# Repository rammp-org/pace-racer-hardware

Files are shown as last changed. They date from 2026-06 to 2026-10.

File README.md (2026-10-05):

# PACE Racer motor controller (KiCad hardware)
Welcome to the official hardware repository for the **PACE V0 (RACER)** motor controller board. This repository contains all KiCad design schematics, layout files, and hardware documentation required to manufacture, test, and interface with the RACER platform. 
The companion firmware for this board is under active development in the companion repository: `pace-racer-firmware`.

**How this repo works:** humans commit KiCad sources; CI (KiBot) runs ERC and DRC on every PR and builds gerbers, BOM, position, ibom, PDFs, STEP and renders. Tagging `VnRm` publishes those as a GitHub Release. See `docs/style-guide.md` for conventions and `docs/decisions/` for the why behind unusual choices.
<div align="center">
PaceRacerV0R1 Splash2

## Documentation & Resources
### Access the [schematics and an interactive board viewer here!](https://kicanvas.org/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)
<a href="https://kicanvas.org/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">
  Access Interactive KiCanvas Board Viewer & Schematics
</a>
---

<div align="left">

## Hardware Architecture Overview

The PACE V0 (RACER) is a high-performance, intelligent 3-phase inverter platform powered by an ESP32-S3. It is engineered to support both high-frequency **Field-Oriented Control (FOC)** and traditional **Trapezoidal (Block) Commutation** strategies. 

``` mermaid
flowchart TD
    %% Upstream USB Environment
    subgraph Upstream ["Upstream Side (Isolated USB Environment)"]
        USB["USB-C Connector<br>(USB1)"] -->|VBUS / GND_USB| VUSB["+5V-USB Rail<br>& GND-USB Rail"]
        VUSB -->|Powers Upstream Side| ISO_In["ADUM3160 Digital Isolator<br>(U4 Upstream Pins)"]
    end

    %% Galvanic Isolation Barrier
    subgraph Barrier ["Galvanic Isolation Boundary"]
        ISO_In -.->|Optical/Magnetic Data Isolation| ISO_Out["ADUM3160 Digital Isolator<br>(U4 Downstream Pins)"]
        SW3{"SW3 Switch<br>(DPDT)"}
    end

    %% High Voltage Input Power Stage
    subgraph HV_Stage ["High-Voltage Input Power Stage"]
        BATT["+BATT Input Rail<br>(48V Nominal Target)"] --> Caps["DC-Link Capacitor Buffers<br>(100V Continuous Rating Limit)"]
        Caps --> XLBuck["XL7015E1 Buck Converter<br>(U6 Stage)"]
    end

    %% Main Logic Subsystems
    subgraph Logic_Rails ["Downstream Logic & Control Subsystem"]
        XLBuck -->|Step Down| V5["+5V Local Rail"]
        
        V5 -->|Linear Regulation| AMS["AMS1117-3.3 LDO (U5)"]
        AMS -->|Logic Power| V33["+3V3 Main MCU Rail"]
        
        V5 -->|Precision Division| REF["REF35160 Reference IC (U7)"]
        REF -->|ADC Baseline Shift| V16["1V6-REF Precision Rail"]
        
        V33 -->|Powers MCU| MCU["ESP32-S3 Processing Core<br>(System GND)"]
        V16 -->|Shunt Offset Bias| MCU
        ISO_Out -->|Isolated USB Signals| MCU
    end

    %% Isolation Mode Controls
    VUSB -->|Route Bus Voltage| SW3
    SW3 -->|Flipped State: Breaks Ground Loops| Logic_Rails
```

### 1. Processing & Inverter Stage
* **Core MCU**: An ESP32-S3-WROOM-1 module handles raw motor control mathematics, wireless telemetry, and hardware interrupt management.
* **Gate Driver**: A TI DRV8353SRTAT 3-phase gate driver provides independent high-side/low-side drive configurations, hardware fault line triggers, and runtime register adjustments via SPI.
* **Power MOSFETs**: 6x ISC0802NLSATMA1 MOSFETs are structured in a traditional 3-phase half-bridge bridge array.
* **Current Sensing**: Dual-purpose inline, low-side 1.0 mΩ current sense shunts (`R1`, `R2`, `R3`) are deployed on all three phases to capture fast current waveforms for precision FOC.

### 2. Sensor Framework
* **Rotor Position Feedback**: Supports dual encoder paradigms:
  * High-speed SPI telemetry via the MT6701 Magnetic Rotary Encoder interface.
  * Discrete input lines for standard 3-phase Hall effect sensor elements (`hall-a`, `hall-b`, `hall-c`).
* **Thermal Management**: 4x LM75ADP I2C digital temperature monitors are distributed across key thermal zones on a single I2C bus. Fixed hardware addressing assigns them respectively to `0x4C`, `0x4D`, `0x4E`, and `0x4F`.

### 3. Communications & Safety
* **Wired Networking**: A Wiznet W5500 Ethernet Coprocessor configuration allows stable, high-throughput network communication over a shared high-speed SPI bus.
* **Galvanic Isolation**: The upstream USB-C debugging connection features an ADUM3160BRWZ-RL digital isolation chip to safely separate logic lines from high-voltage battery transient grounds (see `docs/decisions/0001-ground-domains.md`) during live tuning.

---

## Hardware Pin Mapping Reference

This table is generated from the schematic netlist by `tools/gen_readme.py` and checked in CI. Do not edit it by hand.
Net names follow `docs/style-guide.md` (lowercase domain-kebab); the firmware `hal_pins.h` should use these names.

<!-- BEGIN GENERATED: pinmap -->
| MCU pin | Net | Connected to |
| :-- | :-- | :-- |
| IO0/st-boot (pin 27) | `mcu-boot` | R8, SW1 |
| RXD0 (pin 36) | `uart-rx` | J4 |
| TXD0 (pin 37) | `uart-tx` | J4 |
| IO1/adc1-0 (pin 39) | `vref-1v6` | C23, C27, TP24, U2, U7 |
| IO2/adc1-1 (pin 38) | `mcu-io2` | J4 |
| IO3/st-jtag/adc1-2 (pin 15) | `hall-a` | C42, R34 |
| IO4/adc1-3 (pin 4) | `isense-a` | C30, R10 |
| IO5/adc1-4 (pin 5) | `isense-b` | C29, R21 |
| IO6/adc1-5 (pin 6) | `isense-c` | C28, R22 |
| IO7/adc1-6 (pin 7) | `pwm-c-low` | R26, U2 |
| IO8/adc1-7 (pin 12) | `pwm-a-high` | R31, U2 |
| IO9/adc1-8 (pin 17) | `hall-c` | C40, R25 |
| IO10/adc1-9/FSPI-CS (pin 18) | `eth-spi-cs` | J2, R23 |
| IO11/FSPI-D (pin 19) | `spi-copi` | J2, U2 |
| IO12/FSPI-CLK (pin 20) | `spi-clk` | J2, U2 |
| IO13/FSPI-Q (pin 21) | `spi-cipo` | J2, R17, U2 |
| IO14 (pin 22) | `eth-irq` | J2 |
| IO15 (pin 8) | `pwm-c-high` | R27, U2 |
| IO16 (pin 9) | `pwm-b-low` | R28, U2 |
| IO17 (pin 10) | `pwm-b-high` | R29, U2 |
| IO18 (pin 11) | `pwm-a-low` | R30, U2 |
| IO19/USBD- (pin 13) | `usb-dm` | U4 |
| IO20/USBD+ (pin 14) | `usb-dp` | U4 |
| IO21 (pin 23) | `eth-reset` | J2 |
| IO35 (pin 28) | `enc-spi-cipo` | U12 |
| IO36 (pin 29) | `enc-spi-copi` | J4, U12 |
| IO37 (pin 30) | `enc-spi-clk` | U12 |
| IO38 (pin 31) | `enc-spi-cs` | R24, U12 |
| IO39 (pin 32) | `drv-spi-cs` | U2 |
| IO40 (pin 33) | `drv-fault` | R16, U2 |
| IO41 (pin 34) | `led-green` | D2, J4 |
| IO42 (pin 35) | `led-blue` | D1, J4 |
| IO45/st-spi-v (pin 26) | `i2c-sda` | J4, R39, U10, U11, U8, U9 |
| IO46/st-rom (pin 16) | `hall-b` | C41, R33 |
| IO47 (pin 24) | `drv-enable` | R32, U2 |
| IO48 (pin 25) | `i2c-scl` | J4, R40, U10, U11, U8, U9 |
| EN (pin 3) | `mcu-reset` | R9, SW2 |
<!-- END GENERATED: pinmap -->

---

## Power Distribution & Topology

The RACER PCB layout handles standard heavy industrial current loops alongside sensitive logic rails. Care must be taken during low-level development to understand the distinct ground rules and supply behavior.

* **Main DC Power Stage Input (`+BATT`)**: Accepts high-voltage input up to 60V DC. High and low-frequency buffer capacitor banks are placed immediately across each half-bridge phase to suppress heavy inductive switching ripples up to 25MHz.
* **Logic Subsystem Buck (5V Rail)**: Driven by an XL7015E1 high-voltage buck regulator topology, dropping the high-voltage input down to a common local 5V line.
* **Microcontroller Supply (3.3V Rail)**: An AMS1117-3.3 linear regulator drops the local 5V line to a stable 3.3V rail dedicated to powering the ESP32-S3 and onboard sensors.
* **Analog Ingestion Bias Reference (`vref-1v6`)**: Formed via a REF35160QDBVR high-precision reference generator connected to the 5V line. This outputs a fixed 1.6V reference bias to calibrate the inline current shunt amplifiers, permitting measurement of negative and positive phase currents across the full bi-directional stroke.
* **Isolation Boundary Notice**: The 5V-USB rail is strictly limited to powering the upstream digital isolator components. Flipping the physical isolation switch (`SW3`) cleanly detaches the target ground (`GND`) from development computer USB shields (`GND-USB`) to protect computer infrastructure against high-power faults.

---

## First-Stage Firmware Initialization Blueprint

To quickly bring up prototype firmware on `pace-racer-firmware`, organize your driver initializations using this execution checklist:

### Phase 1: Core Systems & Diagnostic Telemetry
1. Define the physical I/O allocations outlined in the pin reference table.
2. Initialize diagnostic LEDs (`IO41`, `IO42`) to indicate a booting state.
3. Fire up the shared I2C bus over `IO45` and `IO48` to loop and register responses from the four LM75ADP temperature sensor configurations at addresses `0x4C` through `0x4F`. 

### Phase 2: Inverter Protection & Commutation Interfaces
1. Configure `IO40` (`drv-fault`) as an active-low hardware interrupt line. Ensure its handler instantly forces all PWM generation lines into a low (disabled) safety state if triggered.
2. Initialize the main SPI communications bus over pins `spi-copi`, `spi-clk`, and `spi-cipo`. Pull the gate driver chip select (`IO39`) low to configure the DRV8353 operational state registers.
3. For **Field-Oriented Control (FOC)**, configure high-speed SPI capture over the encoder subsystem (`IO35`, `IO37`, `IO38`) to decode magnetic orientation data from the MT6701.
4. For **Trapezoidal Commutation**, establish change-of-state interrupt routines tracking discrete pin changes across Hall effect inputs (`IO3`, `IO46`, `IO9`).

### Phase 3: Ethernet Networking
1. Cycle the hardware reset pin `IO21` to clear the internal registers of the W5500 Ethernet chip.
2. Configure SPI tracking over the controller chip select pin `IO10`.
3. Initialize the raw sockets over network stacks using the standard `eth-irq` (`IO14`) interrupt pin to manage incoming and outgoing network interface events without blocking the high-frequency motor control loops.

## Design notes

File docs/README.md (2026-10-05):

# Documentation

- `media/renders/` — curated board renders and the Blender scene that produced them (Git LFS). The full animation frame set is not tracked; regenerate from the `.blend`.

Planned (see repo hygiene plan):
- `decisions/` — short design decision records (ground topology, isolation switch, each DRC exclusion).
- `style-guide.md` — schematic and layout conventions for the team.
- `bringup.md`, `errata.md` — per-revision bring-up checklist and known issues.

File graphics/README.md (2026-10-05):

# Brand and logo assets

Logo and silkscreen artwork used on the board and in documentation.

- `svg/` — vector logos (RAMMP, ATDev, PaceRacer, DuckSpark, RotoDuk). Import these into KiCad via the Image Converter for silkscreen.
- `png-1x/`, `png-128w/` — raster exports of the above.
- `rotoduck/` — RotoDuk logo rotation sweep (SVG + PNG).
- `src/` — Photoshop source files, stored via Git LFS.

These are not KiCad project files and will move to a shared brand-assets repo once one exists.

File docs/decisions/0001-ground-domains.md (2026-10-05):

# 0001 Ground domains and USB isolation

Status: accepted (V0R1)

The board has two ground nets, not three:

- `GND` is the logic ground and also the power-stage return. The `GNDPWR`
  power symbols on the inverter and power sheets are shorted to `GND` by the
  low-side shunt net ties, so KiCad merges them and ERC reports
  `multiple_net_names`. See 0002.
- `GND-USB` is the upstream, computer-side USB ground. It is separated from
  `GND` by the ADUM3160 digital isolator (U4). The DPDT switch SW3 can bond
  the two grounds for bench work where isolation is not wanted.

Why: a live 48 V power stage with a bench PC attached over USB is the most
common way to destroy a laptop port. Isolation is the default; bonding is a
deliberate switch action.

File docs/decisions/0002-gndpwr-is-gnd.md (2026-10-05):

# 0002 GNDPWR symbols resolve to GND

Status: accepted with an open question

`GNDPWR` symbols are used on the inverter and power sheets to show intent
(power-stage return), but the low-side shunt net ties connect that return to
`GND`, so there is one net. ERC reports one `multiple_net_names` warning for
this and the netlist uses `GND`.

The former `High-Current-GND` net class matched a net (`GND-HC`) that never
existed and was removed in the V1R2 cleanup. The power-stage return relies on
the ground pours, not on a class.

Open question for V2: either replace the `GNDPWR` symbols with `GND` to
silence the warning, or make the split real with a single-point net tie at the
shunts and a dedicated pour. Decide before the next layout change in the
inverter area.

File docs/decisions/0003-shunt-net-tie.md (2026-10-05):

# 0003 Shunt net-tie clearance rule

Status: accepted (V1R2)

The three low-side shunts (R1, R2, R3) use a net-tie footprint (NT1..NT3,
`specific-parts-lib:shunt-net-tie`) to make a Kelvin connection: the sense
net (`shunt-x-n`) and `GND` meet only at the shunt pad. The net-tie pads
intentionally overlap the shunt pads and sit inside the ground pour.

KiCad's default clearance flags those overlaps. Instead of point exclusions
(which were stale after the V1 re-layout), `pace-core.kicad_dru` waives
clearance for anything touching NT1..NT3. The bridge copper inside the
footprint is now part of pad 2 as a custom pad shape, so no free copper
polygon exists and `shorting_items` no longer fires.

Consequence: DRC in CI runs with zero exclusions. If the net tie moves or a
fourth shunt is added, extend the rule condition.

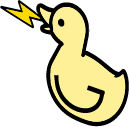
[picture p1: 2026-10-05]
graphics/rotoduck/1x/Generative Object (-180, 30).png

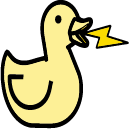
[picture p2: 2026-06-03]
graphics/png-1x/DuckSpark.png

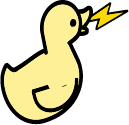
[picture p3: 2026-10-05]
graphics/rotoduck/1x/Generative Object (75, 30).png

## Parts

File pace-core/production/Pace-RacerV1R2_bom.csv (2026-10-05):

Designator | Footprint | Quantity | Value | LCSC Part #
C1, C10, C9 | 0603 | 3 | 100nF
C11, C12, C13 | 1210 | 3 | 4.7uF 100V
C14 | 0603 | 1 | 47nF
C15, C25, C26 | 1206 | 3 | 1uF
C16 | 0402 | 1 | 33nF
C17 | C_Elec_6.3x7.7 | 1 | 100uF 16v | EEEFPV101XAP
C18, C23, C4 | 0603 | 3 | 10uF
C19, C20, C21 | CAP-TH_BD16.0-P7.50-D1.2-FD | 3 | 470uF 100V | C18164658
C2 | 1206 | 1 | 10uF
C24 | 0402 | 1 | 100nF
C27 | 0402 | 1 | .1uF
C28, C29, C30, C40, C41, C42 | 0402 | 6 | 1nF
C3 | 0603 | 1 | 22uF
C31, C32, C33, C34 | 0402 | 4 | 0.1uF
C35 | 1210 | 1 | 2.2uF
C36, C37, C38, C39 | CAP-TH_BD6.3-P2.50-D0.6-FD | 4 | PA100V22M6X9 | C49233038
C6, C7, C8 | 1206 | 3 | 2.2uF 100V
CN1 | CONN-TH_XT60PW-M | 1 | XT60PW-M | C98732
CN2, CN3, CN4, CN5, CN6, CN7 | M3-TH_BD6.0-D4.3 | 6 | SMTSOM330BTR | C5221843
D1 | 0805 | 1 | blue
D2 | 0805 | 1 | green
D3 | 0805 | 1 | red
D4 | D_SMA | 1 | SS310
J1 | 3PhaseMotorPigtail | 1 | MotorOut
J2 | PinSocket_1x09_P2.54mm_Vertical_SMD_Pin1Left | 1 | Wiz5500-Coprocessor-BoB
J4 | PinHeader_2x05_P2.54mm_Vertical_SMD | 1 | Conn_02x05_Odd_Even
L2 | IND-SMD_L10.0-W10.0_SRU1038-100Y | 1 | 100uH 1A | C6684389
Q10, Q11, Q12, Q7, Q8, Q9 | PG-TDSON-8_L5.9-W5.1-P1.27-LS6.1-BL | 6 | ISC0802NLSATMA1 | C3288904
R1, R2, R3 | RES-SMD_L6.3-W3.1-1 | 3 | 1.0mΩ | C41382682
R10, R21, R22, R25, R33, R34 | 0402 | 6 | 100R
R11, R12, R13 | 0402 | 3 | 5k
R14 | 0402 | 1 | 30k 1%
R15 | 0402 | 1 | 10k 1%
R16, R17, R18, R19, R20, R23, R24, R26, R27, R28, R29, R30, R31, R32, R35, R36, R37, R38, R39, R40 | 0402 | 20 | 10k
R4, R5, R8, R9 | 0402 | 4 | 5k1
R6, R7 | 0402 | 2 | 0
SW1, SW2 | KEY-SMD_4P-L4.2-W3.2-P2.20-LS4.6 | 2 | SKRPACE010 | C139797
SW3 | SW-SMD_MST22D18G2 | 1 | DPDT | C2906280
TP18, TP19, TP20, TP24, TP25 | TestPoint_Pad_D2.0mm | 5 | TestPoint
U1 | WIRELM-SMD_ESP32-S3-WROOM-1 | 1 | ESP32-S3-WROOM-1 | C2913205
U10, U11, U8, U9 | TSSOP-8_L3.0-W3.0-P0.65-LS4.9-BL | 4 | LM75ADP,118 | C843694
U12, U13 | CONN-SMD_SM06B-SRSS-TB-LF-SN | 2 | SM06B-SRSS-TB | C160405
U2 | WQFN-40_L6.0-W6.0-P0.50-TL-EP4.2 | 1 | DRV8353SRTAT | C2150480
U3 | SOT-666 | 1 | USBLC6-2P6
U4 | SOIC-16_L10.3-W7.5-P1.27-LS10.3-BL | 1 | ADUM3160BRWZ-RL | C284149
U5 | SOT-223-3_L6.5-W3.4-P2.30-LS7.0-BR | 1 | AMS1117-3.3 | C6186
U6 | TO-252-5_L6.6-W5.8-P1.27-TL | 1 | XL7015E1 | C73013
U7 | SOT-23-6 | 1 | REF35160QDBVR
USB1 | USB-C-SMD_TYPEC-303-ACP16 | 1 | TYPEC-303-ACP16 | C720628

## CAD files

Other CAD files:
docs/media/renders/racer-v0r1-ethernet.blend

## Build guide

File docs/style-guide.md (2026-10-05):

# Hardware style guide

This is the house style for KiCad projects. It exists so a reviewer can tell
"different" from "wrong" in under a minute. When a rule is broken on purpose,
write a decision record in `docs/decisions/` and link it from the schematic note.

## Repository

- Humans commit sources; CI produces everything else. Never commit gerbers, PDFs,
  STEP, ibom or renders. They come from KiBot on every PR and are attached to a
  GitHub Release on tags.
- Revision scheme is `VnRm` (`V1R2`). The git tag, the `REV` text variable, the
  silkscreen and the fab zip name are all that string. CI sets `REV` from the tag.
- Large binaries (Blender, PSD, video, curated renders) go through Git LFS.
- Every fab release gets a tag, a release and an entry in `docs/errata.md`.
- Close KiCad before scripted or git edits to `.kicad_pro`, `.kicad_sch` or
  `.kicad_pcb`. KiCad rewrites those files from memory on save and will
  silently discard outside changes.

## Schematic

- One subsystem per sheet. Sheet title blocks use `${TITLE} - <Subsystem>`,
  `${REV}`, `${COMPANY}` and a one-line purpose in comment 1.
- Net names are lowercase domain-kebab: `<domain>-<signal>[-<qualifier>]`.
  Examples: `pwm-a-high`, `isense-a`, `hall-b`, `enc-spi-cs`, `eth-irq`,
  `i2c-sda`, `usb-dp`, `vref-1v6`, `mcu-boot`. Power nets keep KiCad style:
  `+BATT`, `+5V`, `+3V3`, `GND`, `GND-USB`.
- Every net that crosses a sheet is a hierarchical pin or a global label; never
  rely on a power symbol as a signal.
- Every symbol carries `Manufacturer`, `MPN`, `LCSC Part`, `Datasheet` and
  `Description`. Blank is allowed only for generic passives, and the BOM step
  will show the blank.
- Every ERC exception has a decision record. ERC errors block merge; warnings
  are triaged into `docs/errata.md`.
- Each sheet has a notes block: purpose, key numbers (voltages, currents,
  frequencies), and the calculations behind component values.
- Custom symbols and footprints live in `specific-parts/`. Anything used on a
  second project gets promoted to the shared library repo.

## Layout

- Stackup is defined in Board Setup and matches the fab's stock stackup.
- Net classes drive track and via sizes. Do not hand-set widths that should be
  a class; if a net needs its own width, it needs its own class.
  Current classes (schematic colour in brackets): `Default` 0.2 mm,
  `GND` 0.356 mm (black), `3V3` 0.356 mm (gold), `5V` 0.356 mm (orange),
  `GND-USB` 0.356 mm (blue), `Batt` 1.0 mm (red), `Motor-A/B/C` 1.0 mm
  (yellow / green / blue, also coloured on the board). Colours are part of
  the house style: they make rail and phase mistakes visible at a glance.
- DRC runs with schematic parity and must have zero errors. Custom rules live
  in `pace-core.kicad_dru` with a comment linking the decision record.
  Point exclusions are not used; they go stale when parts move.
- Silkscreen: reference designators readable at 1 mm text, connector pin 1
  marked, polarity marked, `${REV}` and project name on the top silk.
- Test points are numbered `TP<n>` and listed in `docs/bringup.md`.
- Mechanical exchange goes through `mech/` (outline DXF in, board STEP out).

## Review

- Every design change is a PR. The kiri diff is the first thing a reviewer opens.
- The PR template checklist is the definition of done.

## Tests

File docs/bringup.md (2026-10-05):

# Bring-up checklist

Fill in per board serial. Copy this file to `docs/bringup/<rev>-<serial>.md`.

1. Visual: solder bridges on U1, U2, USB1; polarity on C19..C21, D4.
2. Power off: resistance `+BATT` to `GND` (> 10 kΩ), `+5V` to `GND`, `+3V3` to `GND`.
3. Bench supply 12 V, 100 mA limit on `+BATT`: measure `+5V`, `+3V3`, `vref-1v6`.
4. USB with SW3 in isolated position: ESP32 enumerates; measure `GND-USB` to `GND` (open).
5. Flash firmware, LEDs blink, I2C scan finds `0x4C`..`0x4F`.
6. DRV8353 SPI: read device ID; nFAULT high.
7. Encoder SPI: MT6701 angle reads.
8. Motor, 12 V, no load: open-loop spin each direction; check phase current waveforms.
9. Raise to 48 V; thermal check after 5 min at target current.

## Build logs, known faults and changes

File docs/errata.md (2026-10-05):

# Errata and known warnings

## Known ERC/DRC warnings (not errors)

| Check | Count | Why it is tolerated | Fix planned |
| :-- | :-- | :-- | :-- |
| ERC `pin_to_pin` (Unspecified pins) | ~195 | Imported symbols from EasyEDA carry `unspecified` pin types | Assign pin types when parts are promoted to the shared library |
| ERC `lib_symbol_mismatch` | ~15 | Embedded symbol copies drifted from the library | Run *Update Symbols from Library* in the GUI and commit |
| ERC `multiple_net_names` GND/GNDPWR | 1 | See decisions/0002 | Decide GNDPWR split in V2 |
| DRC `lib_footprint_mismatch` | 6 | Embedded footprints drifted from library (C17, USB1, U6, C19..C21) | Run *Update Footprints from Library* and commit |
| DRC `connection_width` on ground pour | 5 | Thin necks in the pour between vias | Widen pour necks in the next layout pass |

## Open design items

- `C5` (47uF 100V) is deliberately not fitted: the buck converter's bulk input capacitance is shared with the motor-drive DC-link caps (C19..C21). Mark it DNP in the schematic so the BOM and parity stay clean.
- Passives lack MPN and LCSC fields; the BOM shows blanks. Fill from the
  assembly quote when the next order is placed.

## Board revision history

| Rev | Built | Notes |
| :-- | :-- | :-- |
| V0R1 | yes | First article. Fab package archived under production/ until retro-tagged. |
| V1R2 | in progress | Re-packaged connectors and layout. |

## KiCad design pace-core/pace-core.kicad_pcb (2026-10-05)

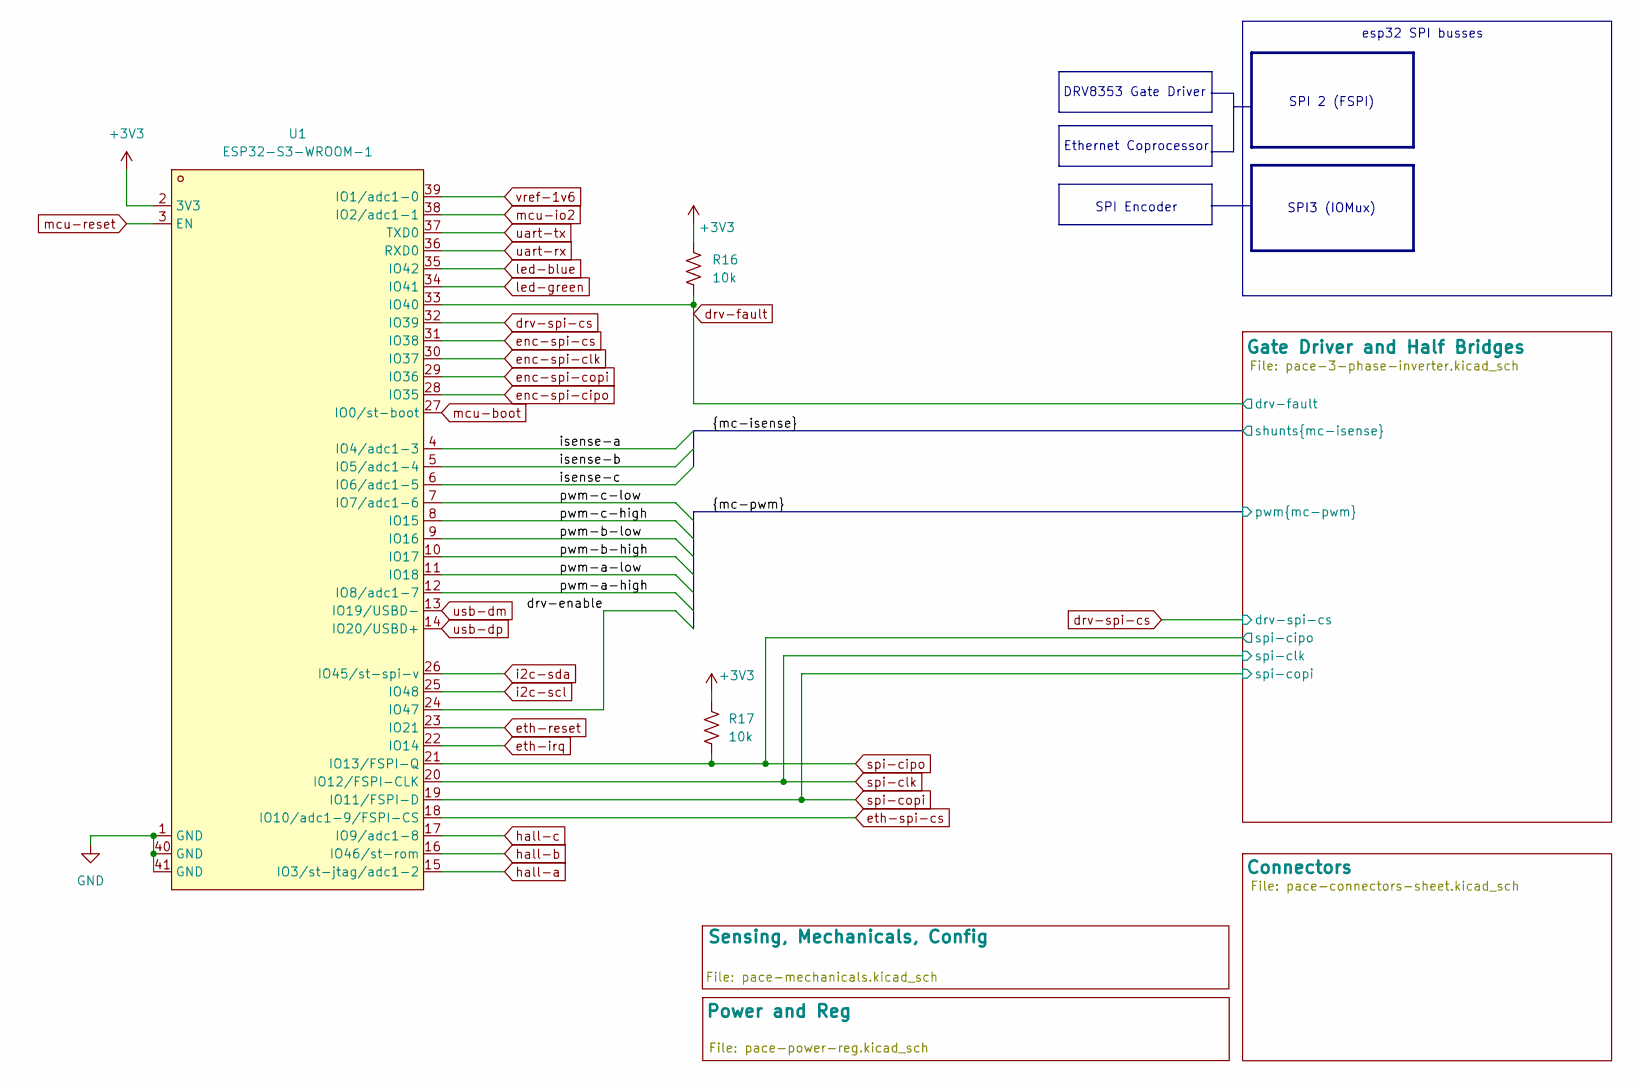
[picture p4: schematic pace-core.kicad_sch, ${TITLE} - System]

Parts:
R16, R17: 10k; R_0402_1005Metric
U1: ESP32-S3-WROOM-1; WIRELM-SMD_ESP32-S3-WROOM-1; MPN ESP32-S3-WROOM-1-N16R2; LCSC Part C2913205

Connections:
+3V3: R16.1, R17.1, U1.2 (3V3); also elsewhere on the board
/drv-enable: U1.24 (IO47); also elsewhere on the board
/isense-a: U1.4 (IO4/adc1-3); also elsewhere on the board
/isense-b: U1.5 (IO5/adc1-4); also elsewhere on the board
/isense-c: U1.6 (IO6/adc1-5); also elsewhere on the board
/pwm-a-high: U1.12 (IO8/adc1-7); also elsewhere on the board
/pwm-a-low: U1.11 (IO18); also elsewhere on the board
/pwm-b-high: U1.10 (IO17); also elsewhere on the board
/pwm-b-low: U1.9 (IO16); also elsewhere on the board
/pwm-c-high: U1.8 (IO15); also elsewhere on the board
/pwm-c-low: U1.7 (IO7/adc1-6); also elsewhere on the board
GND: U1.1 (GND), U1.40 (GND), U1.41 (GND); also elsewhere on the board
drv-fault: R16.2, U1.33 (IO40); also elsewhere on the board
drv-spi-cs: U1.32 (IO39); also elsewhere on the board
enc-spi-cipo: U1.28 (IO35); also elsewhere on the board
enc-spi-clk: U1.30 (IO37); also elsewhere on the board
enc-spi-copi: U1.29 (IO36); also elsewhere on the board
enc-spi-cs: U1.31 (IO38); also elsewhere on the board
eth-irq: U1.22 (IO14); also elsewhere on the board
eth-reset: U1.23 (IO21); also elsewhere on the board
eth-spi-cs: U1.18 (IO10/adc1-9/FSPI-CS); also elsewhere on the board
hall-a: U1.15 (IO3/st-jtag/adc1-2); also elsewhere on the board
hall-b: U1.16 (IO46/st-rom); also elsewhere on the board
hall-c: U1.17 (IO9/adc1-8); also elsewhere on the board
i2c-scl: U1.25 (IO48); also elsewhere on the board
i2c-sda: U1.26 (IO45/st-spi-v); also elsewhere on the board
led-blue: U1.35 (IO42); also elsewhere on the board
led-green: U1.34 (IO41); also elsewhere on the board
mcu-boot: U1.27 (IO0/st-boot); also elsewhere on the board
mcu-io2: U1.38 (IO2/adc1-1); also elsewhere on the board
mcu-reset: U1.3 (EN); also elsewhere on the board
spi-cipo: R17.2, U1.21 (IO13/FSPI-Q); also elsewhere on the board
spi-clk: U1.20 (IO12/FSPI-CLK); also elsewhere on the board
spi-copi: U1.19 (IO11/FSPI-D); also elsewhere on the board
uart-rx: U1.36 (RXD0); also elsewhere on the board
uart-tx: U1.37 (TXD0); also elsewhere on the board
usb-dm: U1.13 (IO19/USBD-); also elsewhere on the board
usb-dp: U1.14 (IO20/USBD+); also elsewhere on the board
vref-1v6: U1.39 (IO1/adc1-0); also elsewhere on the board

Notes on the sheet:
SPI3 (IOMux)
SPI 2 (FSPI)
SPI Encoder
Ethernet Coprocessor
DRV8353 Gate Driver
esp32 SPI busses

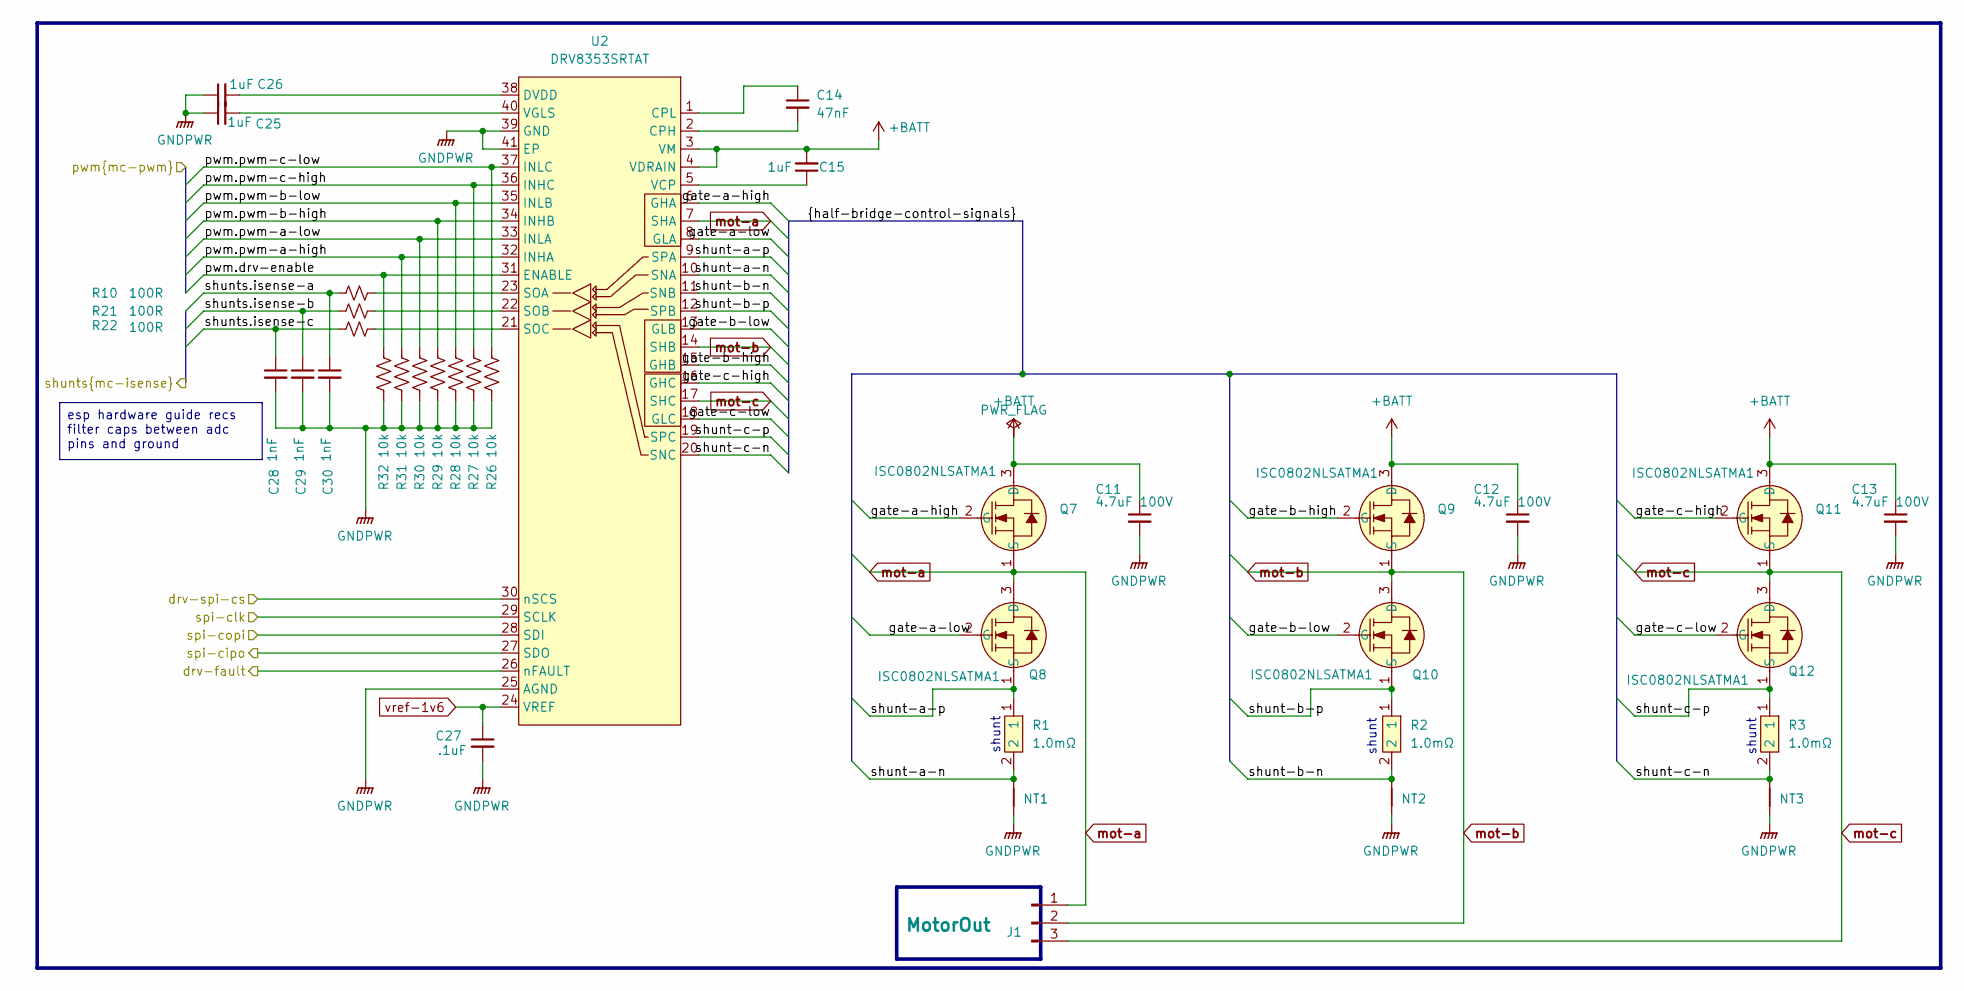
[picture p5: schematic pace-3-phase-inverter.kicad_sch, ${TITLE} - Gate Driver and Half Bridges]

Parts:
C11, C12, C13: 4.7uF 100V; C_1210_3225Metric
C14: 47nF; C_0603_1608Metric
C15, C25, C26: 1uF; C_1206_3216Metric
C27: .1uF; C_0402_1005Metric
C28, C29, C30: 1nF; C_0402_1005Metric
J1: MotorOut; 3PhaseMotorPigtail
NT1, NT2, NT3: NetTie_2; shunt-net-tie
Q7, Q8, Q9, Q10, Q11, Q12: ISC0802NLSATMA1; PG-TDSON-8_L5.9-W5.1-P1.27-LS6.1-BL; MPN ISC0802NLSATMA1; LCSC Part C3288904
R1, R2, R3: 1.0mΩ; RES-SMD_L6.3-W3.1-1; MPN DSLR-M-3-1F; LCSC Part C41382682
R10, R21, R22: 100R; R_0402_1005Metric
R26, R27, R28, R29, R30, R31, R32: 10k; R_0402_1005Metric
U2: DRV8353SRTAT; WQFN-40_L6.0-W6.0-P0.50-TL-EP4.2; MPN DRV8353SRTAT; LCSC Part C2150480

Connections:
+BATT: C11.1, C12.1, C13.1, C15.2, Q7.3 (D), Q9.3 (D), Q11.3 (D), U2.3 (VM), U2.4 (VDRAIN); also elsewhere on the board
/Gate Driver and Half Bridges/gate-a-high: Q7.2 (G), U2.6 (GHA)
/Gate Driver and Half Bridges/gate-a-low: Q8.2 (G), U2.8 (GLA)
/Gate Driver and Half Bridges/gate-b-high: Q9.2 (G), U2.15 (GHB)
/Gate Driver and Half Bridges/gate-b-low: Q10.2 (G), U2.13 (GLB)
/Gate Driver and Half Bridges/gate-c-high: Q11.2 (G), U2.16 (GHC)
/Gate Driver and Half Bridges/gate-c-low: Q12.2 (G), U2.18 (GLC)
/Gate Driver and Half Bridges/shunt-a-n: NT1.2, R1.2, U2.10 (SNA)
/Gate Driver and Half Bridges/shunt-a-p: Q8.1 (S), R1.1, U2.9 (SPA)
/Gate Driver and Half Bridges/shunt-b-n: NT2.2, R2.2, U2.11 (SNB)
/Gate Driver and Half Bridges/shunt-b-p: Q10.1 (S), R2.1, U2.12 (SPB)
/Gate Driver and Half Bridges/shunt-c-n: NT3.2, R3.2, U2.20 (SNC)
/Gate Driver and Half Bridges/shunt-c-p: Q12.1 (S), R3.1, U2.19 (SPC)
/drv-enable: R32.2, U2.31 (ENABLE); also elsewhere on the board
/isense-a: C30.1, R10.1; also elsewhere on the board
/isense-b: C29.1, R21.1; also elsewhere on the board
/isense-c: C28.1, R22.1; also elsewhere on the board
/pwm-a-high: R31.2, U2.32 (INHA); also elsewhere on the board
/pwm-a-low: R30.2, U2.33 (INLA); also elsewhere on the board
/pwm-b-high: R29.2, U2.34 (INHB); also elsewhere on the board
/pwm-b-low: R28.2, U2.35 (INLB); also elsewhere on the board
/pwm-c-high: R27.2, U2.36 (INHC); also elsewhere on the board
/pwm-c-low: R26.2, U2.37 (INLC); also elsewhere on the board
GND: C11.2, C12.2, C13.2, C25.1, C26.1, C27.2, C28.2, C29.2, C30.2, NT1.1, NT2.1, NT3.1, R26.1, R27.1, R28.1, R29.1, R30.1, R31.1, R32.1, U2.25 (AGND), U2.39 (GND), U2.41 (EP); also elsewhere on the board
unnamed: C14.2, U2.2 (CPH)
unnamed: C14.1, U2.1 (CPL)
unnamed: C26.2, U2.38 (DVDD)
unnamed: R10.2, U2.23 (SOA)
unnamed: R21.2, U2.22 (SOB)
unnamed: R22.2, U2.21 (SOC)
unnamed: C15.1, U2.5 (VCP)
unnamed: C25.2, U2.40 (VGLS)
drv-fault: U2.26 (nFAULT); also elsewhere on the board
drv-spi-cs: U2.30 (nSCS); also elsewhere on the board
mot-a: J1.1, Q7.1 (S), Q8.3 (D), U2.7 (SHA)
mot-b: J1.2, Q9.1 (S), Q10.3 (D), U2.14 (SHB)
mot-c: J1.3, Q11.1 (S), Q12.3 (D), U2.17 (SHC)
spi-cipo: U2.27 (SDO); also elsewhere on the board
spi-clk: U2.29 (SCLK); also elsewhere on the board
spi-copi: U2.28 (SDI); also elsewhere on the board
vref-1v6: C27.1, U2.24 (VREF); also elsewhere on the board

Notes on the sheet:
shunt
esp hardware guide recs filter caps between adc pins and ground

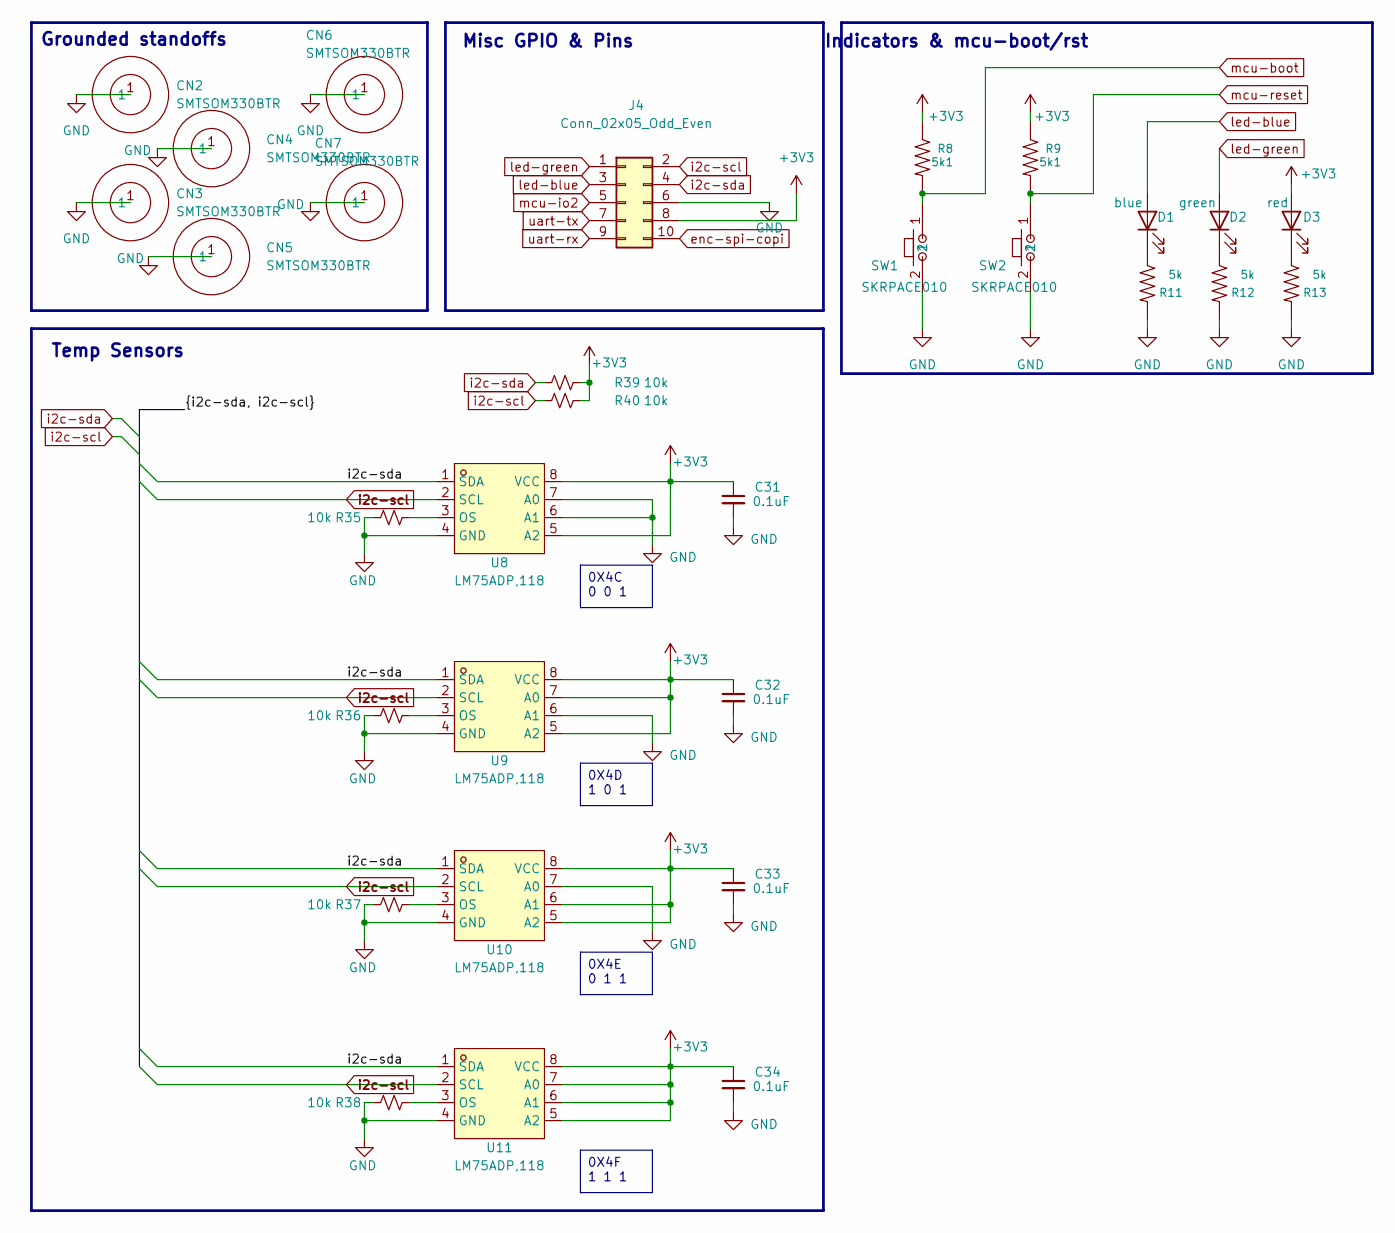
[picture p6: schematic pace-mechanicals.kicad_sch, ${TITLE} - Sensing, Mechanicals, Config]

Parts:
C31, C32, C33, C34: 0.1uF; C_0402_1005Metric
CN2, CN3, CN4, CN5, CN6, CN7: SMTSOM330BTR; M3-TH_BD6.0-D4.3; MPN SMTSOM330BTR; LCSC Part C5221843
D1: blue; LED_0805_2012Metric; LCSC_Part_Number C84259
D2: green; LED_0805_2012Metric; LCSC_Part_Number C84260
D3: red; LED_0805_2012Metric; LCSC_Part_Number C84256
J4: Conn_02x05_Odd_Even; PinHeader_2x05_P2.54mm_Vertical_SMD
R8, R9: 5k1; R_0402_1005Metric; LCSC_Part_Number C25905
R11, R12, R13: 5k; R_0402_1005Metric; LCSC_Part_Number C11702
R35, R36, R37, R38, R39, R40: 10k; R_0402_1005Metric
SW1, SW2: SKRPACE010; KEY-SMD_4P-L4.2-W3.2-P2.20-LS4.6; MPN SKRPACE010; LCSC Part C139797
U8, U9, U10, U11: LM75ADP,118; TSSOP-8_L3.0-W3.0-P0.65-LS4.9-BL; MPN LM75ADP,118; LCSC Part C843694

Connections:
+3V3: C31.1, C32.1, C33.1, C34.1, D3.2 (A), J4.8, R8.1, R9.1, R39.2, R40.2, U8.5 (A2), U8.8 (VCC), U9.5 (A2), U9.7 (A0), U9.8 (VCC), U10.5 (A2), U10.6 (A1), U10.8 (VCC), U11.5 (A2), U11.6 (A1), U11.7 (A0), U11.8 (VCC); also elsewhere on the board
GND: C31.2, C32.2, C33.2, C34.2, CN2.1 (1_1), CN3.1 (1_1), CN4.1 (1_1), CN5.1 (1_1), CN6.1 (1_1), CN7.1 (1_1), J4.6, R11.2, R12.2, R13.2, R35.2, R36.2, R37.2, R38.2, SW1.2, SW2.2, U8.4 (GND), U8.6 (A1), U8.7 (A0), U9.4 (GND), U9.6 (A1), U10.4 (GND), U10.7 (A0), U11.4 (GND); also elsewhere on the board
unnamed: D1.1 (K), R11.1
unnamed: D2.1 (K), R12.1
unnamed: D3.1 (K), R13.1
unnamed: R35.1, U8.3 (OS)
unnamed: R36.1, U9.3 (OS)
unnamed: R37.1, U10.3 (OS)
unnamed: R38.1, U11.3 (OS)
enc-spi-copi: J4.10; also elsewhere on the board
i2c-scl: J4.2, R40.1, U8.2 (SCL), U9.2 (SCL), U10.2 (SCL), U11.2 (SCL); also elsewhere on the board
i2c-sda: J4.4, R39.1, U8.1 (SDA), U9.1 (SDA), U10.1 (SDA), U11.1 (SDA); also elsewhere on the board
led-blue: D1.2 (A), J4.3; also elsewhere on the board
led-green: D2.2 (A), J4.1; also elsewhere on the board
mcu-boot: R8.2, SW1.1; also elsewhere on the board
mcu-io2: J4.5; also elsewhere on the board
mcu-reset: R9.2, SW2.1; also elsewhere on the board
uart-rx: J4.9; also elsewhere on the board
uart-tx: J4.7; also elsewhere on the board

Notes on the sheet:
Temp Sensors
Indicators & mcu-boot/rst
Misc GPIO & Pins
Grounded standoffs
0X4D 1 0 1
0X4E 0 1 1
0X4C 0 0 1
0X4F 1 1 1

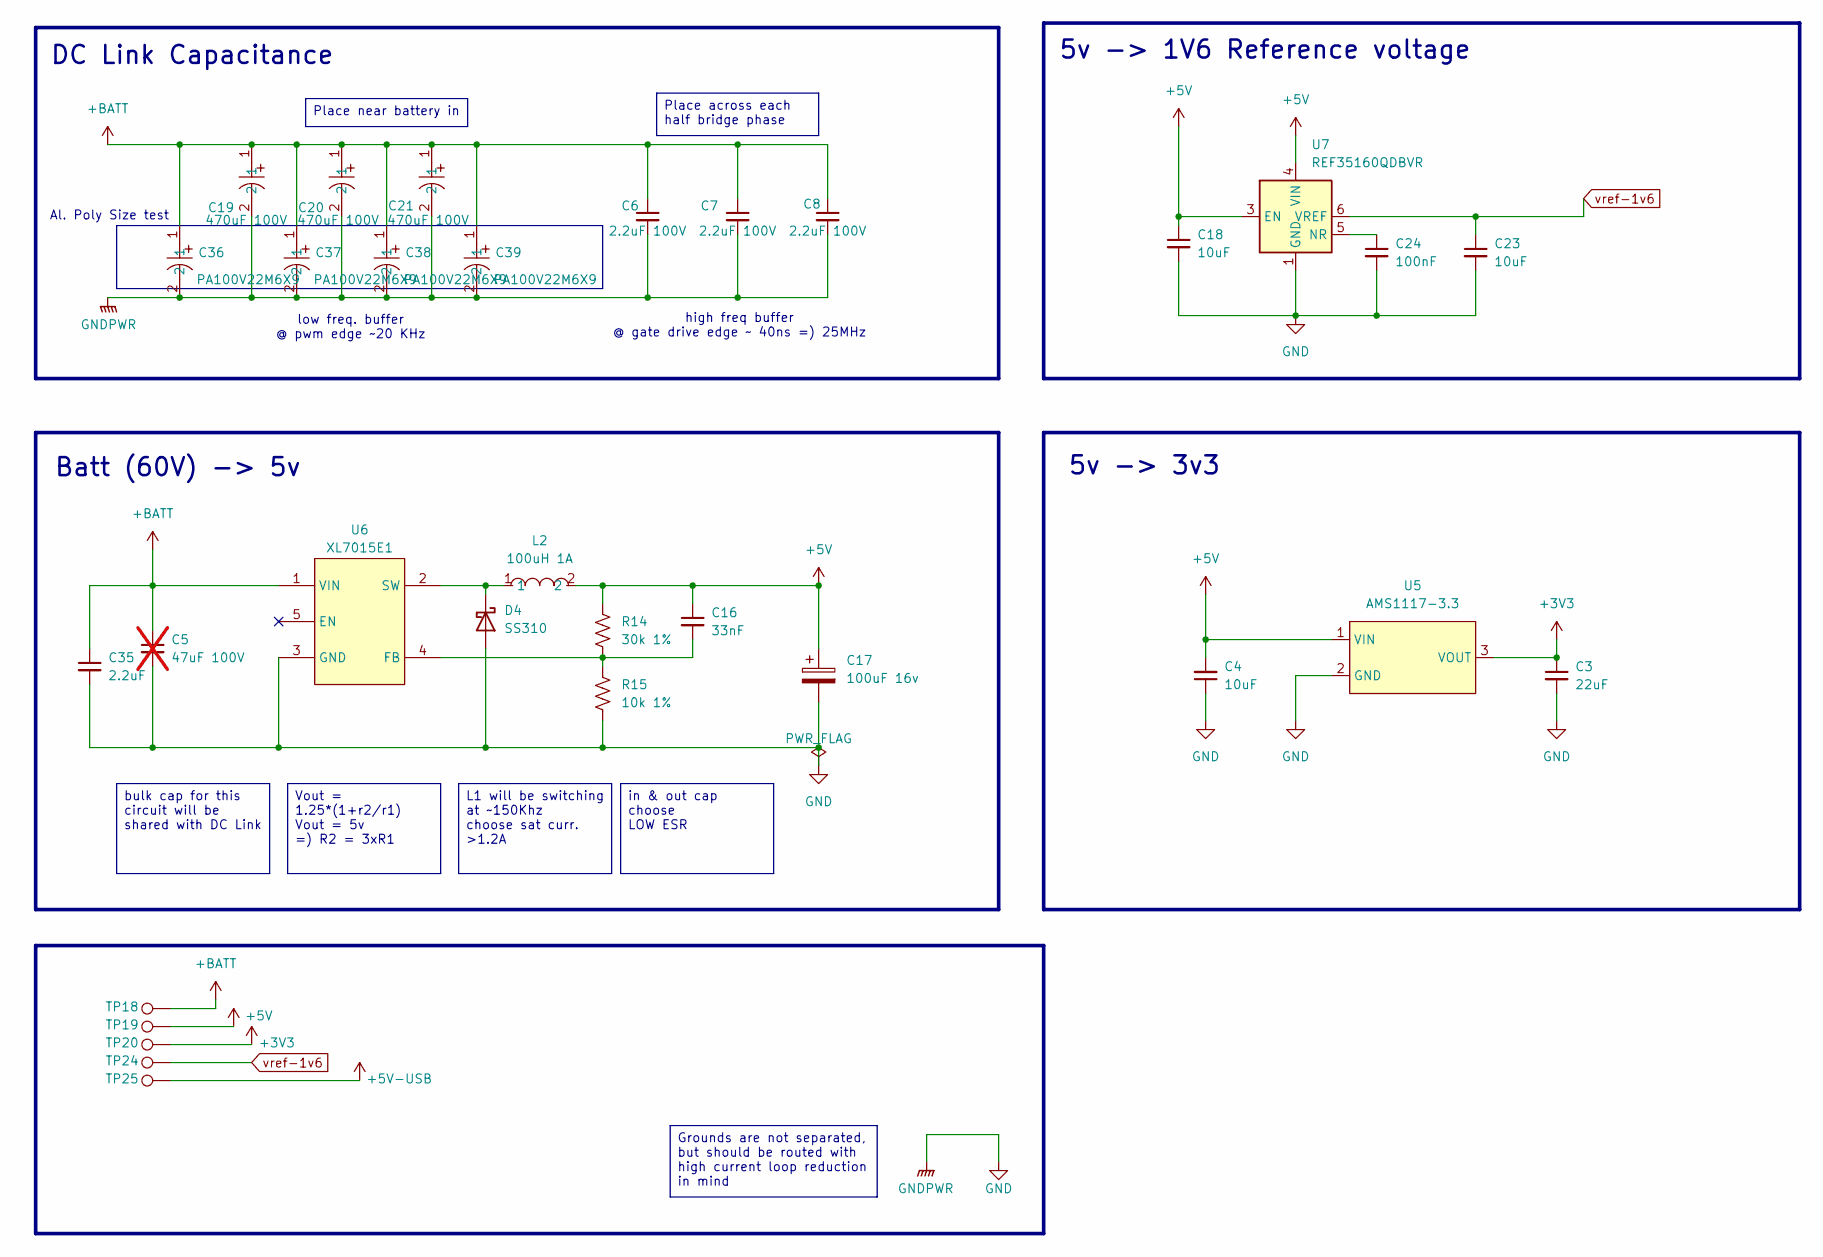
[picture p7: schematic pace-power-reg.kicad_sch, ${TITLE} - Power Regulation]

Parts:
C3: 22uF; C_0603_1608Metric
C4, C18, C23: 10uF; C_0603_1608Metric
C5: 47uF 100V; not fitted
C6, C7, C8: 2.2uF 100V; C_1206_3216Metric
C16: 33nF; C_0402_1005Metric
C17: 100uF 16v; C_Elec_6.3x7.7; MPN EEEFPV101XAP; LCSC Part C178585
C19, C20, C21: 470uF 100V; CAP-TH_BD16.0-P7.50-D1.2-FD; MPN NXH100VB470M16*31.5 LO; LCSC Part C18164658
C24: 100nF; C_0402_1005Metric
C35: 2.2uF; C_1210_3225Metric
C36, C37, C38, C39: PA100V22M6X9; CAP-TH_BD6.3-P2.50-D0.6-FD; MPN PA100V22M6X9; LCSC Part C49233038
D4: SS310; D_SMA; MPN SS310
L2: 100uH 1A; IND-SMD_L10.0-W10.0_SRU1038-100Y; MPN SRU1038-101Y; LCSC Part C6684389
R14: 30k 1%; R_0402_1005Metric
R15: 10k 1%; R_0402_1005Metric
TP18, TP19, TP20, TP24, TP25: TestPoint; TestPoint_Pad_D2.0mm
U5: AMS1117-3.3; SOT-223-3_L6.5-W3.4-P2.30-LS7.0-BR; MPN AMS1117-3.3; LCSC Part C6186
U6: XL7015E1; TO-252-5_L6.6-W5.8-P1.27-TL; MPN XL7015E1; LCSC Part C73013
U7: REF35160QDBVR; SOT-23-6; MPN REF35160QDBVR

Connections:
+3V3: C3.1, TP20.1 (1_1), U5.3 (VOUT); also elsewhere on the board
+5V: C4.2, C16.1, C17.1, C18.1, L2.2, R14.1, TP19.1 (1_1), U5.1 (VIN), U7.3 (EN), U7.4 (VIN); also elsewhere on the board
+5V-USB: TP25.1 (1_1); also elsewhere on the board
+BATT: C5.1, C6.1, C7.1, C8.1, C19.1, C20.1, C21.1, C35.1, C36.1, C37.1, C38.1, C39.1, TP18.1 (1_1), U6.1 (VIN); also elsewhere on the board
GND: C3.2, C4.1, C5.2, C6.2, C7.2, C8.2, C17.2, C18.2, C19.2, C20.2, C21.2, C23.2, C24.2, C35.2, C36.2, C37.2, C38.2, C39.2, D4.2 (A), R15.2, U5.2 (GND), U6.3 (GND), U7.1 (GND), U7.2 (GND); also elsewhere on the board
unnamed: D4.1 (K), L2.1, U6.2 (SW)
unnamed: C16.2, R14.2, R15.1, U6.4 (FB)
unnamed: C24.1, U7.5 (NR)
vref-1v6: C23.1, TP24.1 (1_1), U7.6 (VREF); also elsewhere on the board

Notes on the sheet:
5v -> 1V6 Reference voltage
high freq buffer @ gate drive edge ~ 40ns =) 25MHz
5v -> 3v3
Batt (60V) -> 5v
low freq. buffer @ pwm edge ~20 KHz
DC Link Capacitance
Al. Poly Size test
Place across each half bridge phase
Place near battery in
Grounds are not separated, but should be routed with high current loop reduction in mind
Vout = 1.25*(1+r2/r1) Vout = 5v =) R2 = 3xR1
in & out cap choose LOW ESR
L1 will be switching at ~150Khz choose sat curr. >1.2A
bulk cap for this circuit will be shared with DC Link

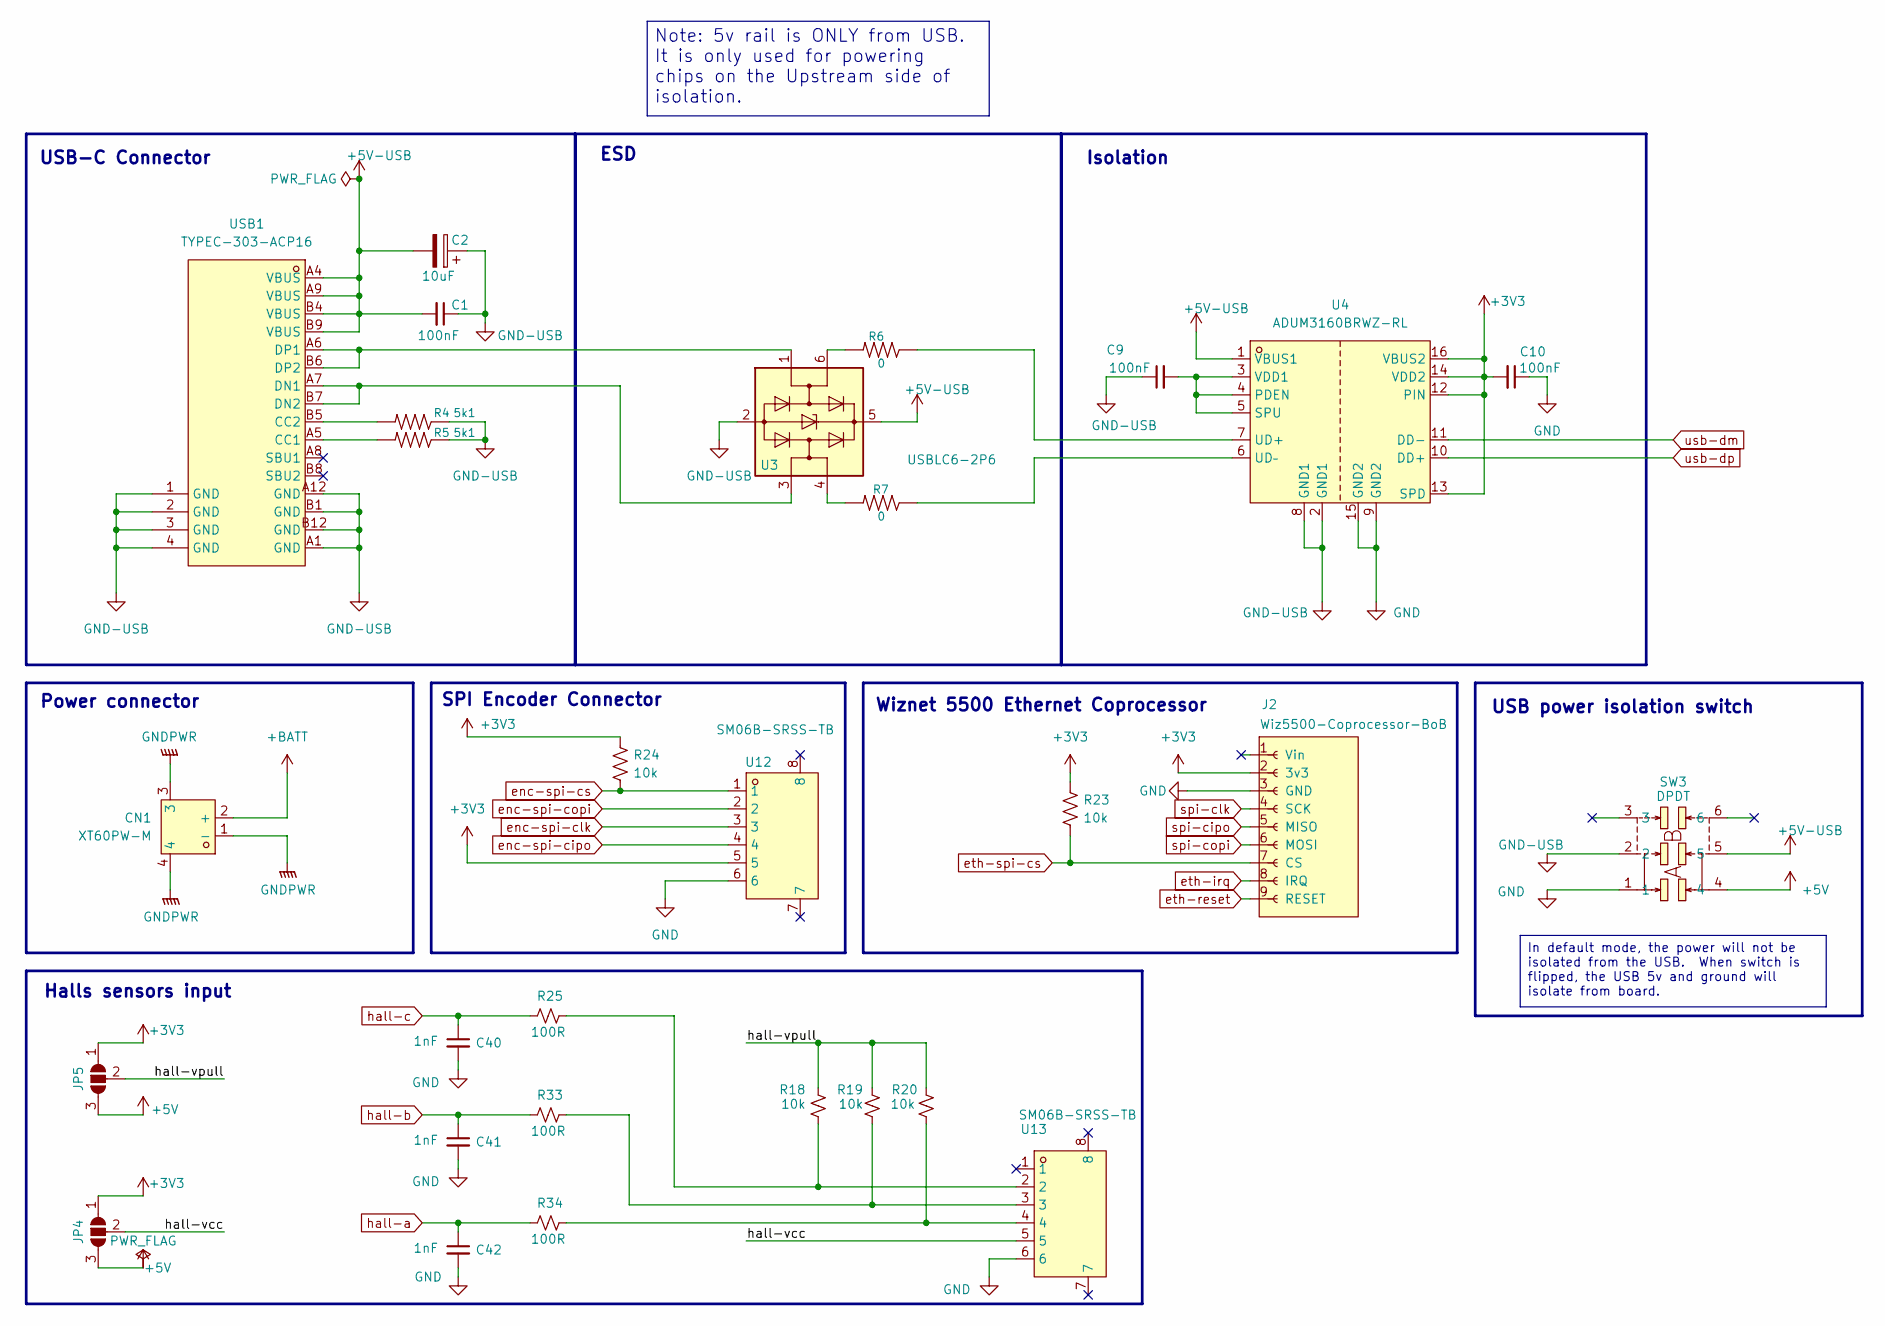
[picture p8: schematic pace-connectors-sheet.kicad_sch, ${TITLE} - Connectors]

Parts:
C1, C9, C10: 100nF; C_0603_1608Metric
C2: 10uF; C_1206_3216Metric
C40, C41, C42: 1nF; C_0402_1005Metric
CN1: XT60PW-M; CONN-TH_XT60PW-M; MPN XT60PW-M; LCSC Part C98732
J2: Wiz5500-Coprocessor-BoB; PinSocket_1x09_P2.54mm_Vertical_SMD_Pin1Left
JP4, JP5: SolderJumper_3_Bridged12; SolderJumper-3_P1.3mm_Open_RoundedPad1.0x1.5mm
R4, R5: 5k1; R_0402_1005Metric; LCSC_Part_Number C25905
R6, R7: 0; R_0402_1005Metric; LCSC_Part_Number C3017451
R18, R19, R20, R23, R24: 10k; R_0402_1005Metric
R25, R33, R34: 100R; R_0402_1005Metric
SW3: DPDT; SW-SMD_MST22D18G2; MPN MST22D18G2 125; LCSC Part C2906280
U3: USBLC6-2P6; SOT-666; MPN USBLC6-2P6; LCSC_Part_Number C2827693
U4: ADUM3160BRWZ-RL; SOIC-16_L10.3-W7.5-P1.27-LS10.3-BL; MPN ADUM3160BRWZ-RL; LCSC Part C284149
U12, U13: SM06B-SRSS-TB; CONN-SMD_SM06B-SRSS-TB-LF-SN; MPN SM06B-SRSS-TB(LF)(SN); LCSC Part C160405
USB1: TYPEC-303-ACP16; USB-C-SMD_TYPEC-303-ACP16; MPN TYPEC-303-ACP16; LCSC Part C720628

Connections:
+3V3: C10.2, J2.2 (3v3), JP4.1 (A), JP5.1 (A), R23.1, R24.1, U4.12 (PIN), U4.13 (SPD), U4.14 (VDD2), U4.16 (VBUS2), U12.5; also elsewhere on the board
+5V: JP4.3 (B), JP5.3 (B), SW3.4; also elsewhere on the board
+5V-USB: C1.2, C2.2, SW3.5, U3.5 (VBUS), U4.1 (VBUS1), USB1.A4 (VBUS), USB1.A9 (VBUS), USB1.B4 (VBUS), USB1.B9 (VBUS); also elsewhere on the board
+BATT: CN1.2 (+); also elsewhere on the board
/Connectors/hall-vcc: JP4.2 (C), U13.5
/Connectors/hall-vpull: JP5.2 (C), R18.2, R19.2, R20.2
GND: C10.1, C40.2, C41.2, C42.2, CN1.1 (-), CN1.3, CN1.4, J2.3 (GND), SW3.1, U4.9 (GND2), U4.15 (GND2), U12.6, U13.6; also elsewhere on the board
GND-USB: C1.1, C2.1, C9.1, R4.1, R5.1, SW3.2, U3.2 (GND), U4.2 (GND1), U4.8 (GND1), USB1.1 (GND), USB1.2 (GND), USB1.3 (GND), USB1.4 (GND), USB1.A1 (GND), USB1.A12 (GND), USB1.B1 (GND), USB1.B12 (GND)
unnamed: R6.2, U3.6 (I/O1)
unnamed: R7.2, U3.4 (I/O2)
unnamed: R18.1, R25.2, U13.2
unnamed: R19.1, R33.2, U13.3
unnamed: R20.1, R34.2, U13.4
unnamed: C9.2, U4.3 (VDD1), U4.4 (PDEN), U4.5 (SPU)
unnamed: R6.1, U4.7 (UD+)
unnamed: R7.1, U4.6 (UD–)
unnamed: R5.2, USB1.A5 (CC1)
unnamed: R4.2, USB1.B5 (CC2)
unnamed: U3.3 (I/O2), USB1.A7 (DN1), USB1.B7 (DN2)
unnamed: U3.1 (I/O1), USB1.A6 (DP1), USB1.B6 (DP2)
enc-spi-cipo: U12.4; also elsewhere on the board
enc-spi-clk: U12.3; also elsewhere on the board
enc-spi-copi: U12.2; also elsewhere on the board
enc-spi-cs: R24.2, U12.1; also elsewhere on the board
eth-irq: J2.8 (IRQ); also elsewhere on the board
eth-reset: J2.9 (RESET); also elsewhere on the board
eth-spi-cs: J2.7 (CS), R23.2; also elsewhere on the board
hall-a: C42.1, R34.1; also elsewhere on the board
hall-b: C41.1, R33.1; also elsewhere on the board
hall-c: C40.1, R25.1; also elsewhere on the board
spi-cipo: J2.5 (MISO); also elsewhere on the board
spi-clk: J2.4 (SCK); also elsewhere on the board
spi-copi: J2.6 (MOSI); also elsewhere on the board
usb-dm: U4.11 (DD-); also elsewhere on the board
usb-dp: U4.10 (DD+); also elsewhere on the board

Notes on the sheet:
Wiznet 5500 Ethernet Coprocessor
Power connector
USB power isolation switch
Halls sensors input
Isolation
USB-C Connector
SPI Encoder Connector
ESD
Note: 5v rail is ONLY from USB. It is only used for powering chips on the Upstream side of isolation.
In default mode, the power will not be isolated from the USB. When switch is flipped, the USB 5v and ground will isolate from board.

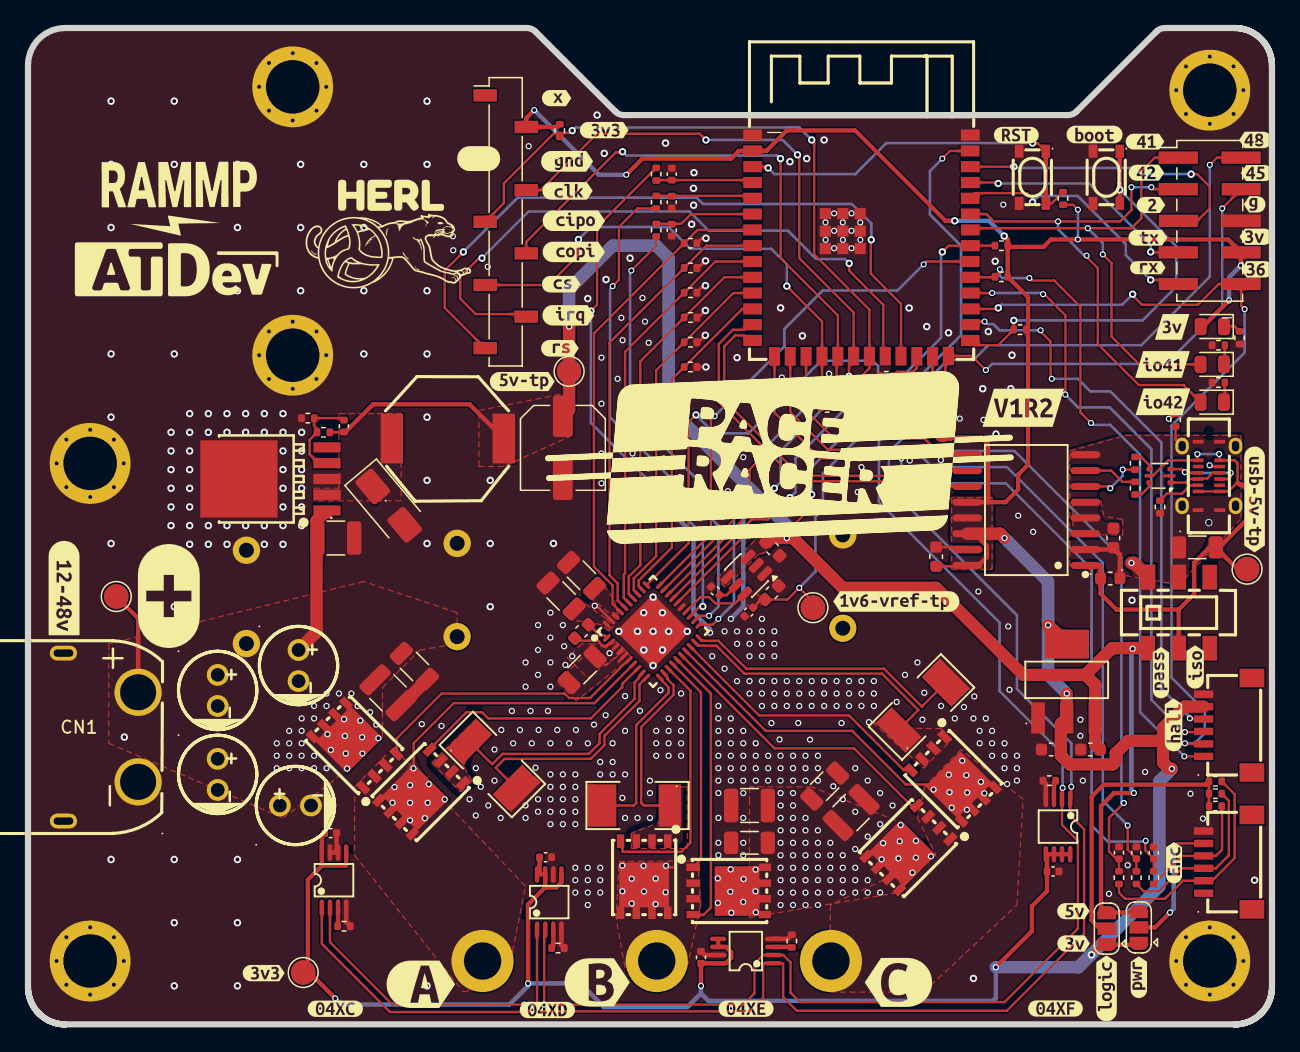
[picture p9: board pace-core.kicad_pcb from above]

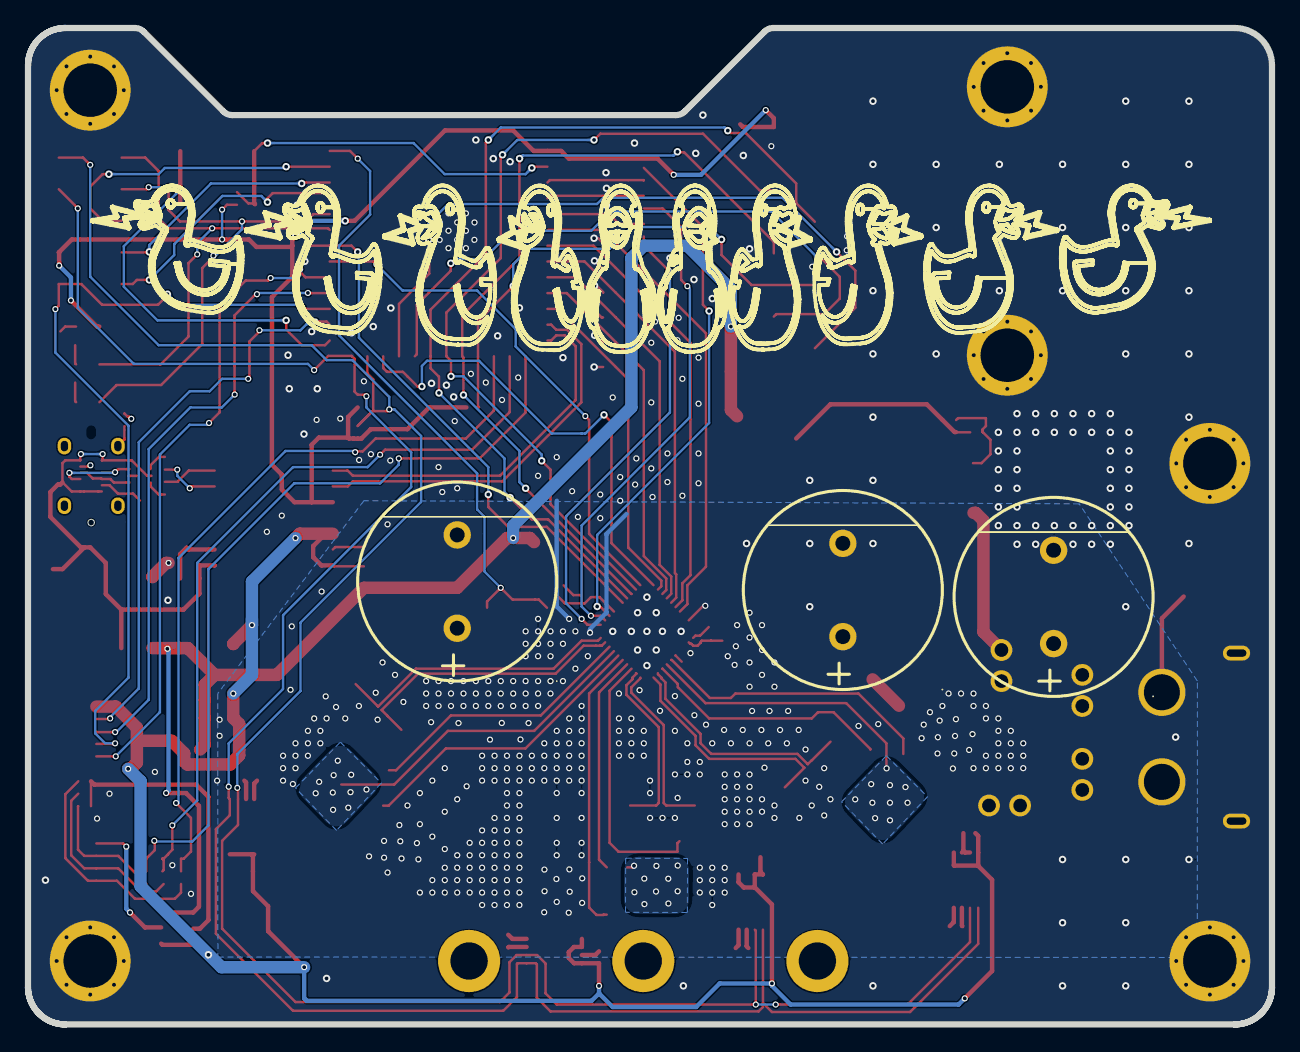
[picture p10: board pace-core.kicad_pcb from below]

Board: 4 copper layers, 100.0 x 80.1 mm, 175 parts (7 on the bottom side), 90 nets.

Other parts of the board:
kibuzzard-6A7D445B: G***; kibuzzard-6A7D445B
kibuzzard-6A7D4481: G***; kibuzzard-6A7D4481
kibuzzard-6A76A5A9: G***; kibuzzard-6A76A5A9
kibuzzard-6A76A5E2: G***; kibuzzard-6A76A5E2
kibuzzard-6A76A5F0: G***; kibuzzard-6A76A5F0
kibuzzard-6A76A7BD: G***; kibuzzard-6A76A7BD
kibuzzard-6A76A7CE: G***; kibuzzard-6A76A7CE
kibuzzard-6A76A8BC: G***; kibuzzard-6A76A8BC
kibuzzard-6A76A9E7: G***; kibuzzard-6A76A9E7
kibuzzard-6A76A71C: G***; kibuzzard-6A76A71C
kibuzzard-6A76A80F: G***; kibuzzard-6A76A80F
kibuzzard-6A76A83C: G***; kibuzzard-6A76A83C
kibuzzard-6A76A86B: G***; kibuzzard-6A76A86B
kibuzzard-6A76A548: G***; kibuzzard-6A76A548
kibuzzard-6A76A790: G***; kibuzzard-6A76A790
kibuzzard-6A76A802: G***; kibuzzard-6A76A802
kibuzzard-6A76A904: G***; kibuzzard-6A76A904
kibuzzard-6A76A908: G***; kibuzzard-6A76A908
kibuzzard-6A76A991: G***; kibuzzard-6A76A991
kibuzzard-6A76AA0A: G***; kibuzzard-6A76AA0A
kibuzzard-6A76AA3B: G***; kibuzzard-6A76AA3B
kibuzzard-6A76AAA5: G***; kibuzzard-6A76AAA5
kibuzzard-6A76AAC0: G***; kibuzzard-6A76AAC0
kibuzzard-6A76AAE1: G***; kibuzzard-6A76AAE1
kibuzzard-6A76AB0C: G***; kibuzzard-6A76AB0C
kibuzzard-6A76AB7D: G***; kibuzzard-6A76AB7D
kibuzzard-6A76AB8B: G***; kibuzzard-6A76AB8B
kibuzzard-6A76AB97: G***; kibuzzard-6A76AB97
kibuzzard-6A76ABC4: G***; kibuzzard-6A76ABC4
kibuzzard-6A76AD5A: G***; kibuzzard-6A76AD5A
kibuzzard-6A76AD71: G***; kibuzzard-6A76AD71
kibuzzard-6A793D41: G***; kibuzzard-6A793D41
kibuzzard-6A1928DD: G***; kibuzzard-6A1928DD
kibuzzard-6A1931C8: G***; kibuzzard-6A1931C8
kibuzzard-6A1931CD: G***; kibuzzard-6A1931CD
kibuzzard-6A1931D7: G***; kibuzzard-6A1931D7
kibuzzard-6A1931DC: G***; kibuzzard-6A1931DC
kibuzzard-6A1931E2: G***; kibuzzard-6A1931E2
kibuzzard-6A1931EE: G***; kibuzzard-6A1931EE
kibuzzard-6A79703A: G***; kibuzzard-6A79703A
kibuzzard-6A192903: G***; kibuzzard-6A192903
kibuzzard-6A192914: G***; kibuzzard-6A192914
kibuzzard-6A193405: G***; kibuzzard-6A193405
kibuzzard-6A193411: G***; kibuzzard-6A193411
kibuzzard-6A193434: G***; kibuzzard-6A193434
kibuzzard-6A769215: G***; kibuzzard-6A769215
kibuzzard-6A797050: G***; kibuzzard-6A797050

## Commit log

2026-06-03 manufacturing pcba order submitted
    [.step, Pace-RacerV0R1_bom.csv, Pace-RacerV0R1_designators.csv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]
2026-06-04 Enhance README with detailed hardware and firmware info
    Expanded documentation for the PACE V0 motor controller board, including hardware architecture, pin mapping, power distribution, and firmware initialization guidelines.
2026-06-04 Enhance README with interactive board viewer link
    Updated the README to include a link with an image for accessing the interactive KiCanvas board viewer and schematics.
2026-06-04 updated shematic with test point image
    [pace-mechanicals.kicad_sch]
2026-06-05 update for kicad 10 instead of 9
2026-06-05 tidy up
    [pace-connectors-sheet.kicad_sch, pace-core.kicad_pcb, pace-mechanicals.kicad_sch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]
2026-10-05 design checkpoint: v1 repackage — new connectors, footprints, and lay… (#1)
    * design checkpoint: v1 repackage — new connectors, footprints, and layout updates
    - Add JST SH/SR series, XT30PW-M, TH cap, and SOT-23-3 footprints with 3D models
    - Update connectors, power-reg, and mechanicals schematic sheets
    - Rework PCB layout and update board STEP exports (r0 updated, r2 added)
    - Regenerate interactive BOM
    * update connectors schematic and PCB layout, refresh r2 STEP export
    * Repo hygiene, CI as source of truth, and V1R2 design cleanup
    Repository
    - Sources only in pace-core/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
    [.step, Pace-RacerV1R2_bom.csv, Pace-RacerV1R2_designators.csv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]
